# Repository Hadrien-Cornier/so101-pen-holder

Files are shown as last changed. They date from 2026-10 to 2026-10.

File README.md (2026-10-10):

# SO-101 pen holder

This is a printed sleeve that holds a pen on the stock gripper of the SO-101 robot arm. You print 4 small parts. You do not buy parts, and you do not take the arm apart.

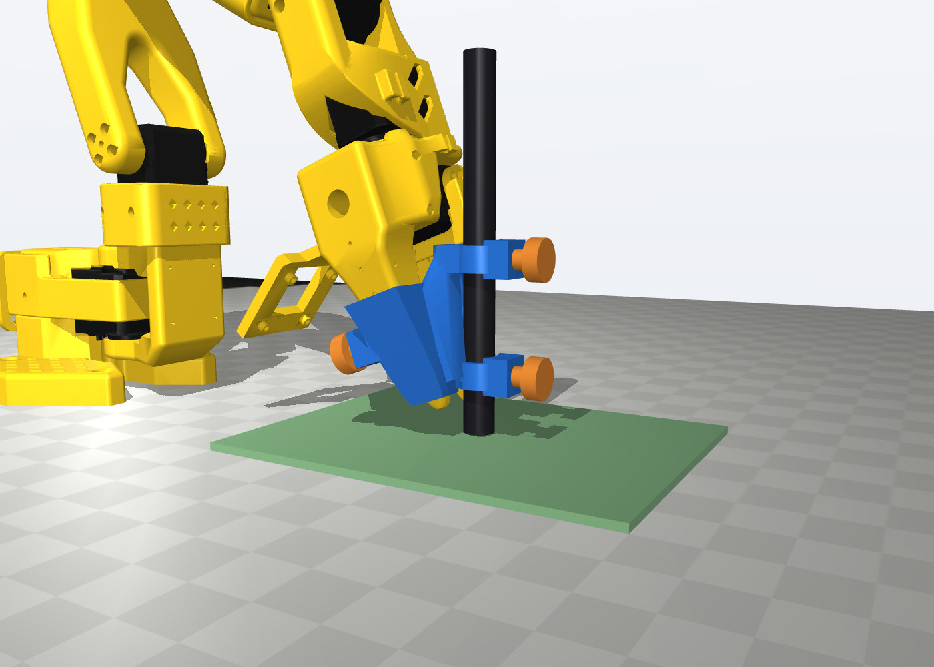
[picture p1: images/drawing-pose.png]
The SO-101 in a drawing pose with the pen holder. The blue sleeve is on the fixed finger, and the pen is vertical on the paper.


> [!NOTE]
> **Status: the first printed set fits, but nothing is measured yet.** The parts pass every collision check in CAD. The first set printed in PLA, the sleeve slid onto my finger, and the screws turned in on the first try, with no change to the design. I felt no play by hand. I have not measured the play, the tip position or the hold. Every number on this page is a design value, not a measurement. If you print the holder, you can report the result in an issue.

| | |
|---|---|
| Printed parts | 1 sleeve (27 g) and 3 identical M8 thumbscrews (2 g each) |
| Parts to buy | none |
| Pens | any round pen from 8 to 13 mm, for example a Wacom Pen 4K, a BIC 4-Colour or a Pilot V5 |
| Tablet | the Wacom Intuos S (CTL-4100), ±0.25 mm. See [Measure the tip with a Wacom tablet](#measure-the-tip-with-a-wacom-tablet). |
| Changes to the arm | none. The sleeve slides onto the fixed finger. |
| Fits | the stock SO-101 follower gripper (`Wrist_Roll_Follower_SO101`) |
| License | Apache-2.0 |

The holder on the stock gripper, from four sides. The blue sleeve is the printed part, and the orange parts are the printed thumbscrews:

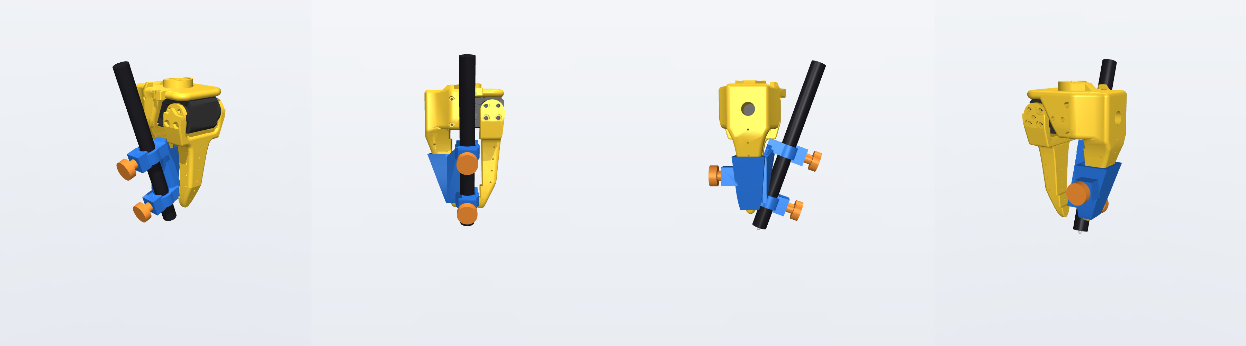
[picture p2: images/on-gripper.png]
The pen holder on the stock SO-101 gripper, seen from four sides


## The first print and the first fit

The first set is printed, and the sleeve is on my SO-101. The two pictures below play the full videos in a loop, with no sound. The MP4 files have a better quality.

<table>
<tr>
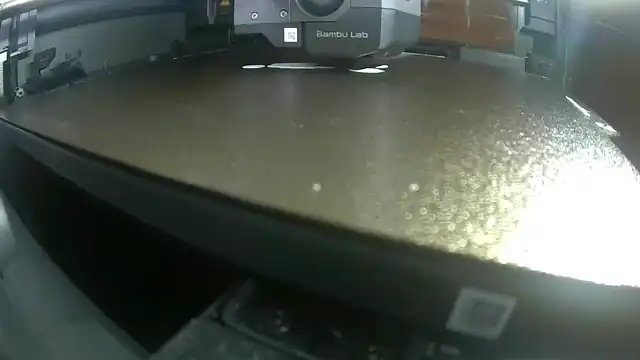
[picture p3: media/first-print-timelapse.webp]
Time-lapse of the print: four thumbscrews, two thread coupons and the sleeve grow on the bed of a Bambu Lab printer. The sleeve stands up on tree supports.
<td align="center" valign="middle"></td>
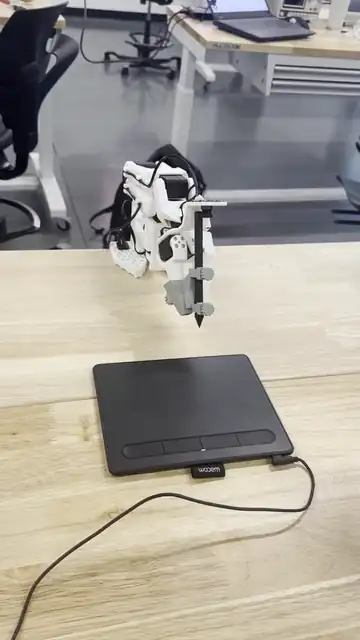
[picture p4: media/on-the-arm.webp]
The printed sleeve on the fixed finger of the SO-101. A pen is in both clamps, and the Wacom Intuos S tablet is in front of the arm.
<td align="center" valign="middle"></td>
</tr>
<tr>
<td align="center"><b>The print</b>, 15 s time-lapse<br><a href="https://github.com/Hadrien-Cornier/so101-pen-holder/raw/main/media/first-print-timelapse.mp4">Download the MP4</a> (3.4 MB)</td>
<td align="center"><b>The holder on the arm</b>, 13 s<br><a href="https://github.com/Hadrien-Cornier/so101-pen-holder/raw/main/media/on-the-arm.mp4">Download the MP4</a> (2.6 MB)</td>
</tr>
</table>

What the videos show:

- **The print.** A Bambu Lab printer makes the 4 thumbscrews, two thread coupons and the sleeve in one job. The screws print head down. The sleeve stands up, and the printer builds tree supports under it.
- **The holder on the arm.** The sleeve is on the stock fixed finger, and the pen is in both clamps with a thumbscrew on each clamp. The Wacom Intuos S is in front of the arm, and the pen tip is above it.

The result of the first try:

- **The sleeve fitted.** It slid onto the stock fixed finger with no filing and no change to the design.
- **The screws fitted.** They turned in on the first try, with no change to `FIT_THREAD`.
- **No play by hand.** I felt no play at the pen. This is a hand test, not a measurement.
- **The printer followed the settings.** The first set printed in PLA with the settings in [Print the parts](#print-the-parts).

I have not measured these points yet: the play at the tip, the tip position, the hold of the sleeve in the down direction, and a reading on the tablet. The videos show no drawing and no tablet reading. The [Limits](#limits) section lists the open points.

## Why a pen on a robot arm

A drawing is a simple test of how accurately an arm follows a path. When the arm leaves the path, the line on the paper shows it. You can see the error without a log file or a plot, and you can compare two controllers on the same sheet.

I use this test in my SO-101 control project. In a typical drawing pose, an error of 1 mrad on every joint moves the pen tip by about 0.3 mm on the paper. With the joint errors of my best controller, I expect a drawing error of about 1.2 mm RMS.

The test works only if the holder adds no error of its own. My first pen was taped into the gripper. It had two problems:

- **The pen moved in the tape.** When the paper pulled on the tip, the pen moved, and that movement looked like an arm error.
- **The tip position was not known.** My best fit of the tip position had a residual of 3 mm. That is more than the error that I want to see.

I searched GitHub, the SO-ARM100 repository, Printables, Thingiverse, MakerWorld, Cults3D and the LeRobot forum. I found grippers and camera mounts, but no pen holder for the SO-100 or the SO-101. So I designed one.

Ink shows the shape of an error, but it gives no numbers and no times. To measure the tip, I also bought a Wacom drawing tablet. The holder takes its pen. The section [Measure the tip with a Wacom tablet](#measure-the-tip-with-a-wacom-tablet) explains why.

The holder has five goals:

| Goal | Why |
|---|---|
| No play between the pen and the arm | The paper drag must not move the pen in the holder. |
| A known tip position | The arm model must know where the tip is. A guess adds an error to every point. |
| Any common pen | You can use the pen that you have, and a Wacom pen on a drawing tablet. |
| Nothing to buy, no change to the arm | Anybody with an SO-101 can try it in an afternoon. |
| A small print | A short print time and a small risk of a failed print. |

## Why this design

I made five designs. Each design fixed a problem of the one before it. The image shows all five with the same camera.

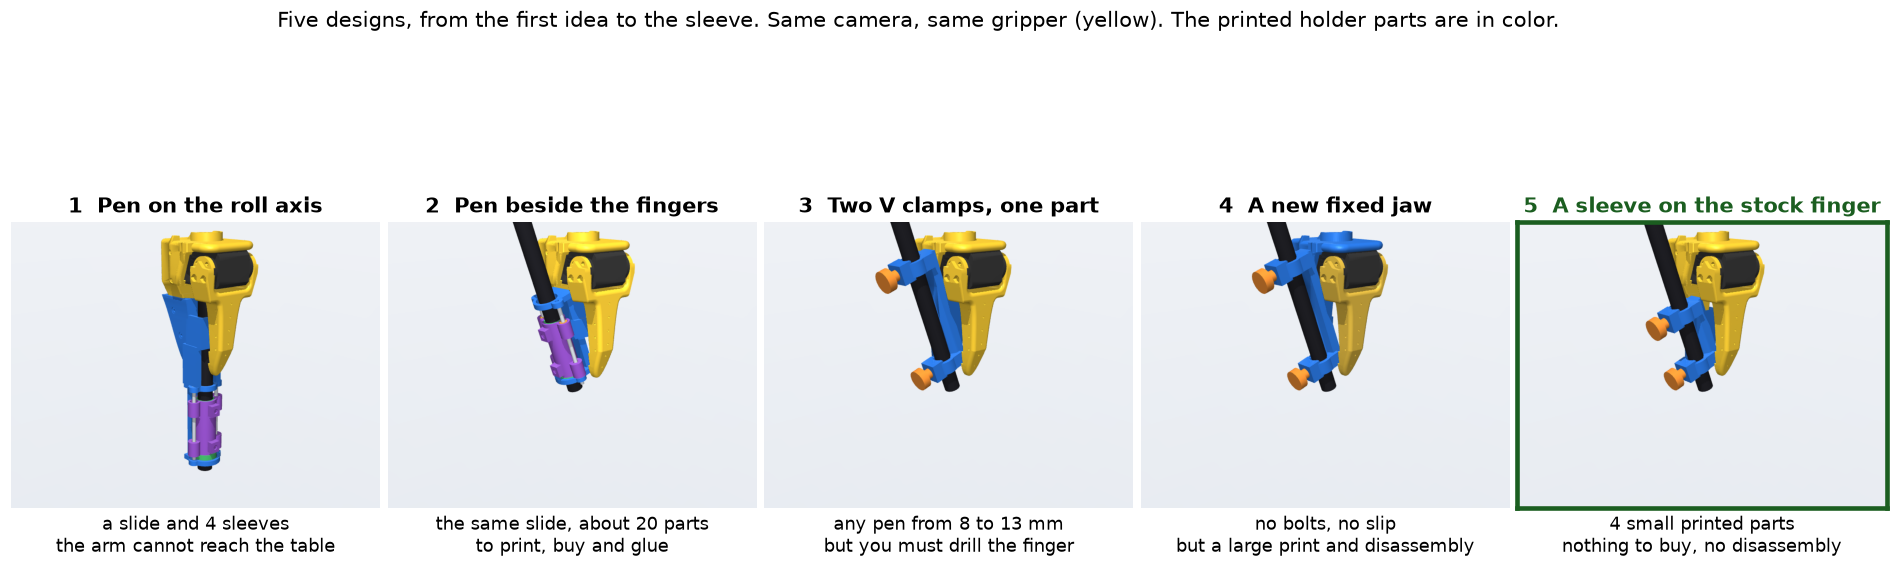
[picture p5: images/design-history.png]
Five designs on the same gripper with the same camera: the pen on the roll axis, the pen beside the fingers, two V clamps on one part, a new fixed jaw, and the sleeve on the stock finger.


1. **The pen on the roll axis.** The pen went down through the gripper, on a slide that let it rest on the paper by its own weight. On the full arm model, the arm could not reach a table at the level of its base.
2. **The pen beside the fingers.** I compared seven ways to attach the pen. The best layout puts the pen beside the fingers and leans it 20° out of the open side of the jaws. It reaches the most paper, and the tip stays 6 mm from the roll axis. But the slide needed about 20 parts: printed parts, steel shafts, bronze bushings and glue.
3. **Two V clamps on one part.** I removed the slide. A soft pad under the paper does its job. Two V clamps hold the pen at two points far apart, so the pen cannot tilt. One clamp design fits every pen from 8 to 13 mm. But to hold the part on the finger, you had to drill two holes in the finger for metal bolts.
4. **A new fixed jaw.** I joined the clamps to a copy of the official fixed jaw. Nothing can slip, but it is a large print, and you must take the gripper apart to change the jaw.
5. **A sleeve on the stock finger.** The clamps sit on a small sleeve that slides onto the finger. This is the design in this repository.

The last choice was between three ways to attach the same clamps:

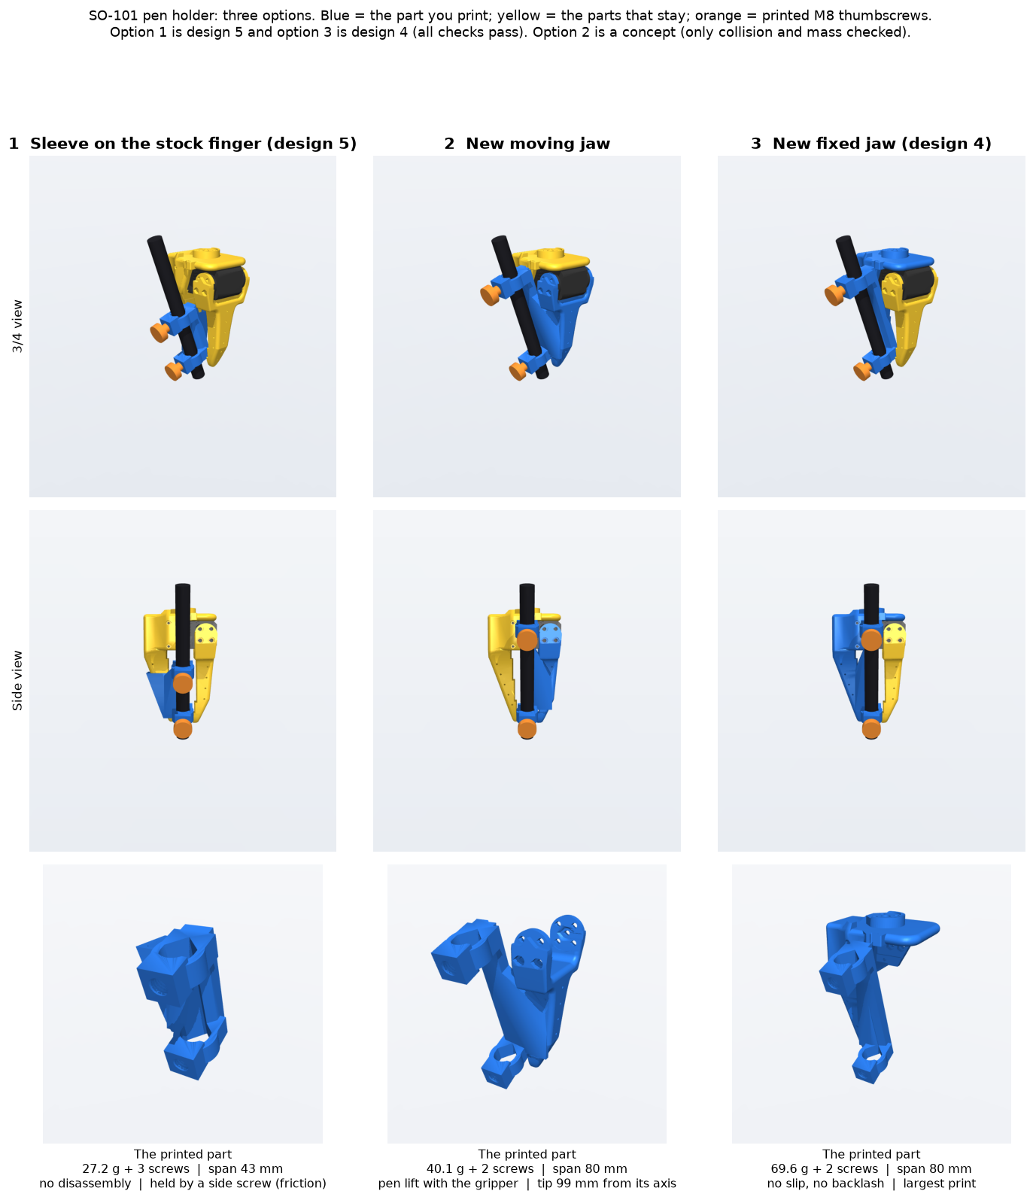
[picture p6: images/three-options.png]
The three final options side by side: a sleeve on the stock finger, a new moving jaw, and a new fixed jaw. The printed part is blue.


| | Sleeve on the finger (this design) | New moving jaw | New fixed jaw |
|---|---|---|---|
| Printed plastic | 34 g | 44 g | 74 g |
| Take the gripper apart | no | the moving jaw | the full gripper |
| Hold on the arm | wedge seat and friction | jaw screws | jaw screws |
| Play at the tip | none in the clamps | the backlash of the gripper motor, unless the jaw presses on a stop | none |
| Distance between the clamps | 43 mm | 80 mm | 80 mm |

I chose the sleeve for three reasons:

- **Anybody can try it.** You add one module to an arm that you already have. You do not open the gripper, and you can remove the sleeve in a minute.
- **It is the smallest print.** It uses less than half the plastic of a new fixed jaw.
- **The main load makes the hold tighter.** When the pen touches the paper, the paper pushes the sleeve up onto its seat on the finger.

The cost of the sleeve is a shorter distance between the clamps (43 mm), and a hold in the down direction that uses friction only. The [Limits](#limits) section gives the details.

## What you need

- An FDM 3D printer and about 34 g of filament. The first set printed in PLA and fitted. I did not compare filaments, so I do not recommend one.
- A soft pad, 2 to 5 mm thick, to put under the paper. For example, use a mouse pad, a felt sheet or thin foam. The pen is fixed in the holder, so the pad takes up small errors in the height of the arm. On a Wacom tablet, do not use the pad.
- A stock SO-101 follower arm. The optional compliant gripper has a different finger, and the sleeve does not fit it.

## Print the parts

The files are in [`print/`](print/). Each file is already placed in its print orientation, so do not turn it in the slicer:

| File | Quantity | Mass | Purpose | Print orientation |
|---|---|---|---|---|
| [`thread_coupon.stl`](print/thread_coupon.stl) | 1 | 2 g | A short piece of the M8 thread, to test the screw fit on your printer | The hole is horizontal, like the thread holes of the sleeve. |
| [`thumbscrew.stl`](print/thumbscrew.stl) | 3, and 1 spare | 2 g each | Two screws press the pen into the clamps. One screw presses the finger. | Head down |
| [`sleeve.stl`](print/sleeve.stl) | 1 | 27 g | The sleeve with the two pen clamps | Pen axis vertical, tip end up |

The first set printed in PLA with these settings, and it fitted on the first try. I did not compare other settings:

| Setting | Value | Why |
|---|---|---|
| Layer height | 0.2 mm | The usual value for a 0.4 mm nozzle. Thinner layers give smoother threads, but the print takes longer. |
| Walls | 4, which is 1.6 mm | The clamp rings (3 mm) and the side walls (2.6 mm) become solid, and the threads (0.68 mm deep) are in solid plastic. |
| Infill | 40 % for the sleeve and the coupon, 100 % for the screws | The infill changes only the thick areas. A solid screw is stronger, and it is only 2.1 g of plastic. |

The masses in the table use 4 walls and 40 % infill.

### Supports for the sleeve

The print orientation of `sleeve.stl` keeps the supports off the faces that set the pen position. The sleeve stands on the end of the upper thread boss. Red faces need support:

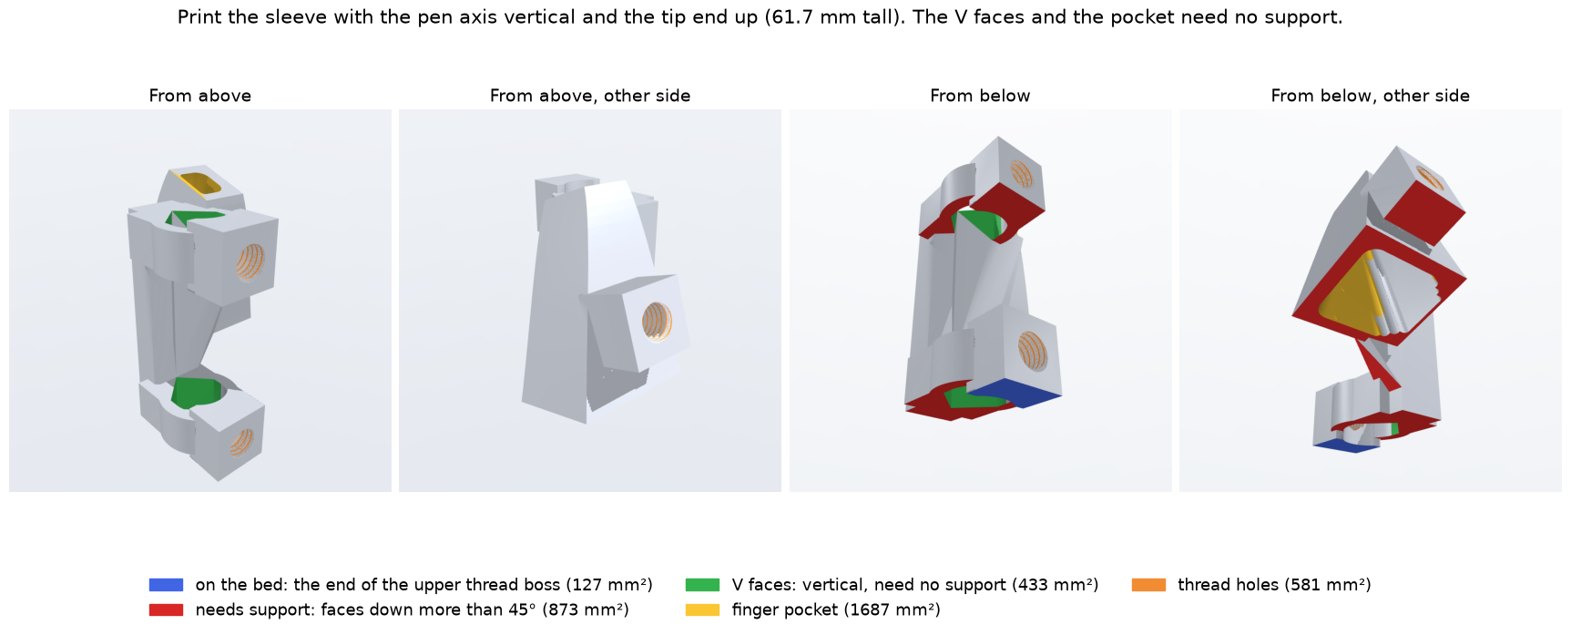
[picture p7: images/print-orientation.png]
The sleeve in its print orientation, from above and from below. Red faces need support. The green V faces and the yellow finger pocket need none. The blue face stands on the bed.


- **The V faces need no support.** They are vertical in this orientation. A support mark of 0.2 mm on a V face of the lower clamp would move the tip by about 0.3 mm.
- **The finger pocket needs no support.** The pocket has only 0.15 mm of clearance, so support marks in it would stop the sleeve from sliding onto the finger.
- **The supports stand outside the pocket.** [`cad/print_orientation.py`](cad/print_orientation.py) traces a column down from each face that needs support. Of 873 mm² of these faces, 586 mm² have columns on the bed and 287 mm² have columns on outside faces of the sleeve. No column passes through the pocket.
- **Block the supports in the three thread holes.** The holes are 8 mm wide and horizontal, and supports would damage the threads.
- **Use a brim.** The sleeve is 62 mm tall and stands on a face of only 127 mm².

The support analysis comes from the CAD model. The first print used this orientation and these support rules, and the sleeve and the screws fitted. That is one print on one printer, and I did not print the other orientations. The check uses a limit of 45° from vertical for supports, and your slicer can use a different limit. [`results/print_orientation.json`](results/print_orientation.json) compares 8 orientations.

### Print order

1. Print `thread_coupon.stl` and one `thumbscrew.stl`.
2. Turn the screw into the coupon by hand.
3. If the screw is too tight or too loose, change `FIT_THREAD` in [`cad/build.py`](cad/build.py). Then [rebuild the parts](#rebuild-the-parts) and print the coupon again.
4. Print `sleeve.stl` and three more thumbscrews. One screw is a spare.

## Fit the holder

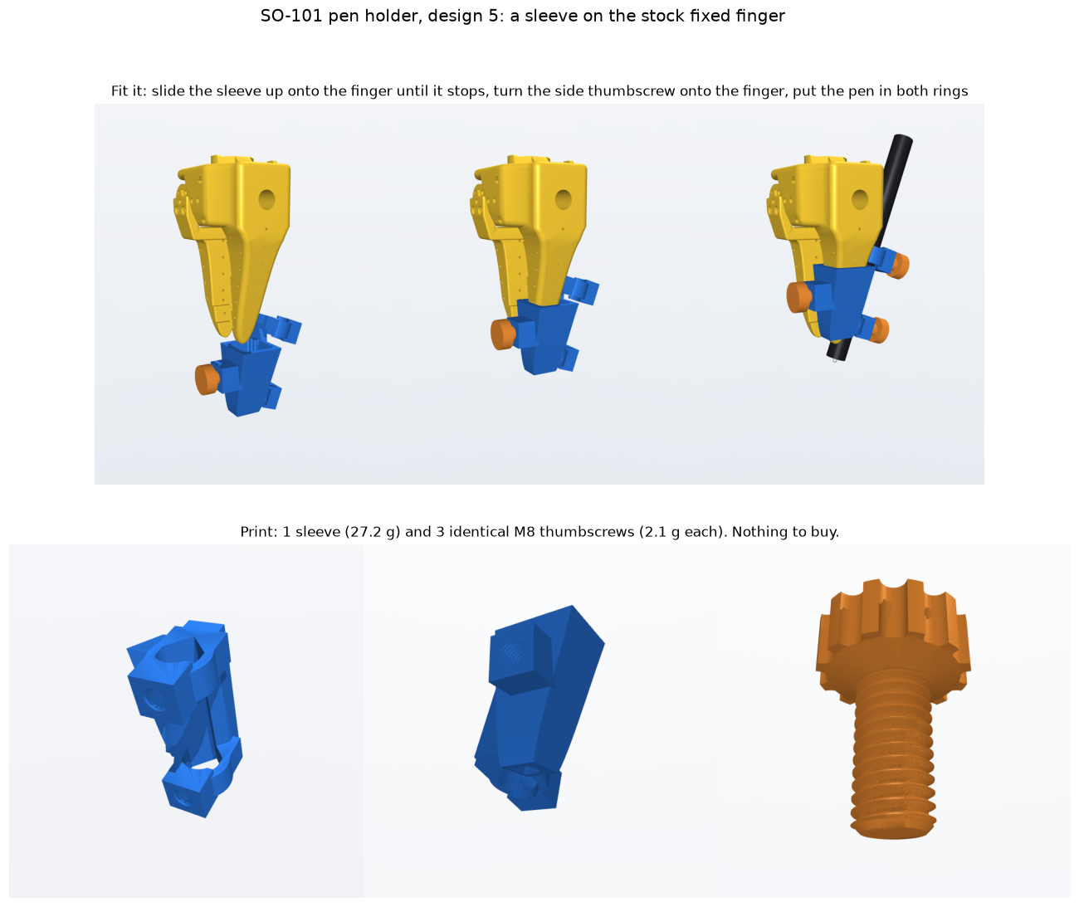
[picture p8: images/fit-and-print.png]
Top: the sleeve slides up onto the stock fixed finger, then the pen goes into both rings. Bottom: the printed sleeve and the thumbscrew.


1. Open the gripper fully.
2. Slide the sleeve up onto the end of the fixed finger until it stops. The two pen clamps go on the open side of the jaws.
3. Turn the side thumbscrew until it is tight on the finger.
4. Push the pen through both clamp rings.
5. Set the pen tip 21 mm below the bottom face of the lower ring, measured along the pen. That puts the tip at the design position for every pen.
6. Turn each pen thumbscrew until it touches the pen. Then turn it a quarter turn more.
7. Put the soft pad under the paper.

> [!CAUTION]
> Do not command the gripper to close fully while the sleeve is on the finger. The moving jaw touches the lower clamp ring at 0.015 rad from closed. If the motor pushes harder, it presses on the ring.

## How the holder works

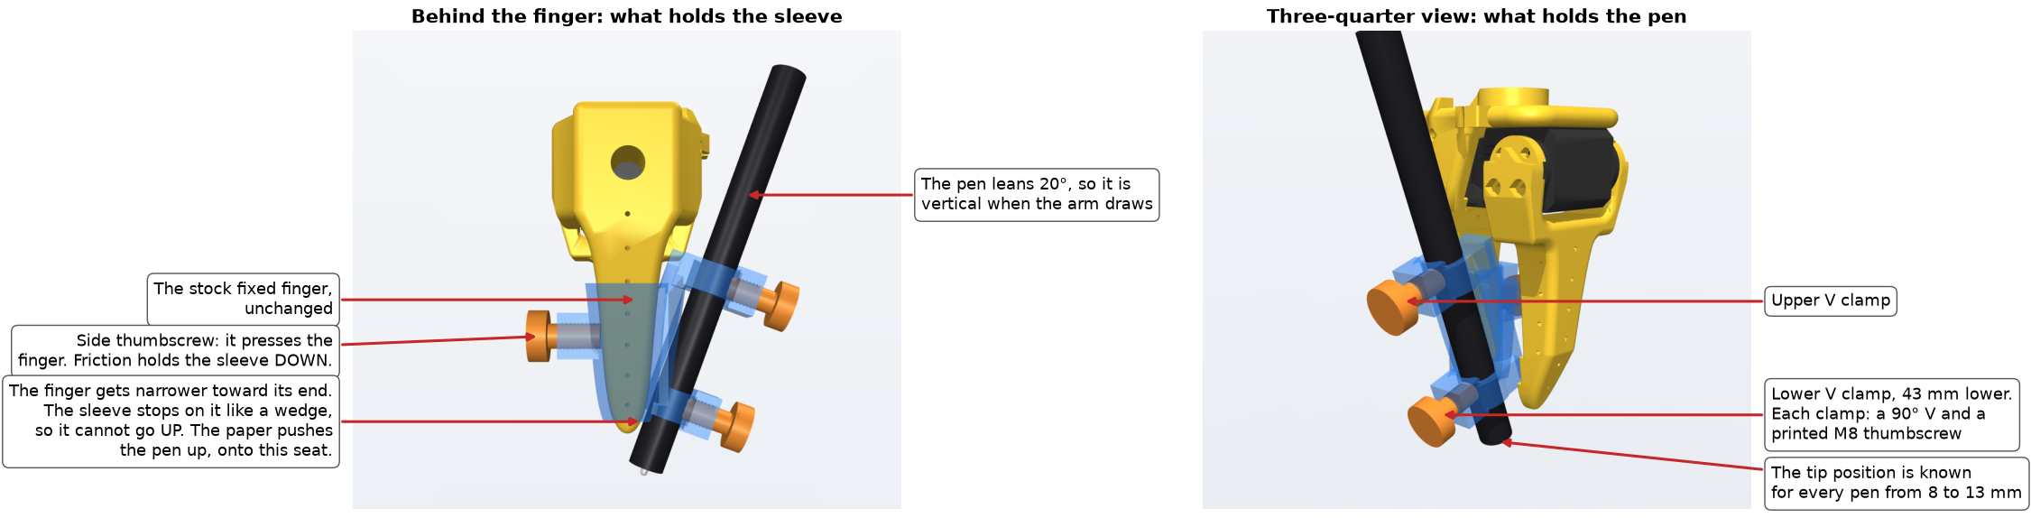
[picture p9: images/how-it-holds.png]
Left: a view from behind the fixed finger. The sleeve is see-through, so the finger shows inside it. Right: a three-quarter view of the two pen clamps.


The sleeve holds on the finger in three directions:

- **Up:** the finger gets narrower toward its end in both directions. The pocket of the sleeve has the shape of the finger, so the sleeve stops on it like a wedge. The paper pushes the pen up, which pushes the sleeve harder onto this seat.
- **Down:** the side thumbscrew presses one side of the finger and pushes the other side against the inner wall of the sleeve. Friction on both sides holds the sleeve. A hand-tight printed M8 screw probably presses with 50 to 100 N. With a friction coefficient of about 0.3 on two faces, the hold is about 30 to 60 N. The sleeve, the screws and a pen weigh about 0.45 N. These are estimates, not measurements.
- **Sideways:** the pocket fits the finger with 0.15 mm of clearance. The side screw removes the clearance in its direction. The wedge seat removes it in the other directions when the paper pushes up.

The pen is held by two clamps 43 mm apart. Each clamp is a ring with a 90° V on the gripper side and a printed M8 thumbscrew on the other side. The screw pushes the pen into the V. A round pen in a V touches it on two lines, so it can sit in only one position. There is no play to remove.

## Pens and the tip position

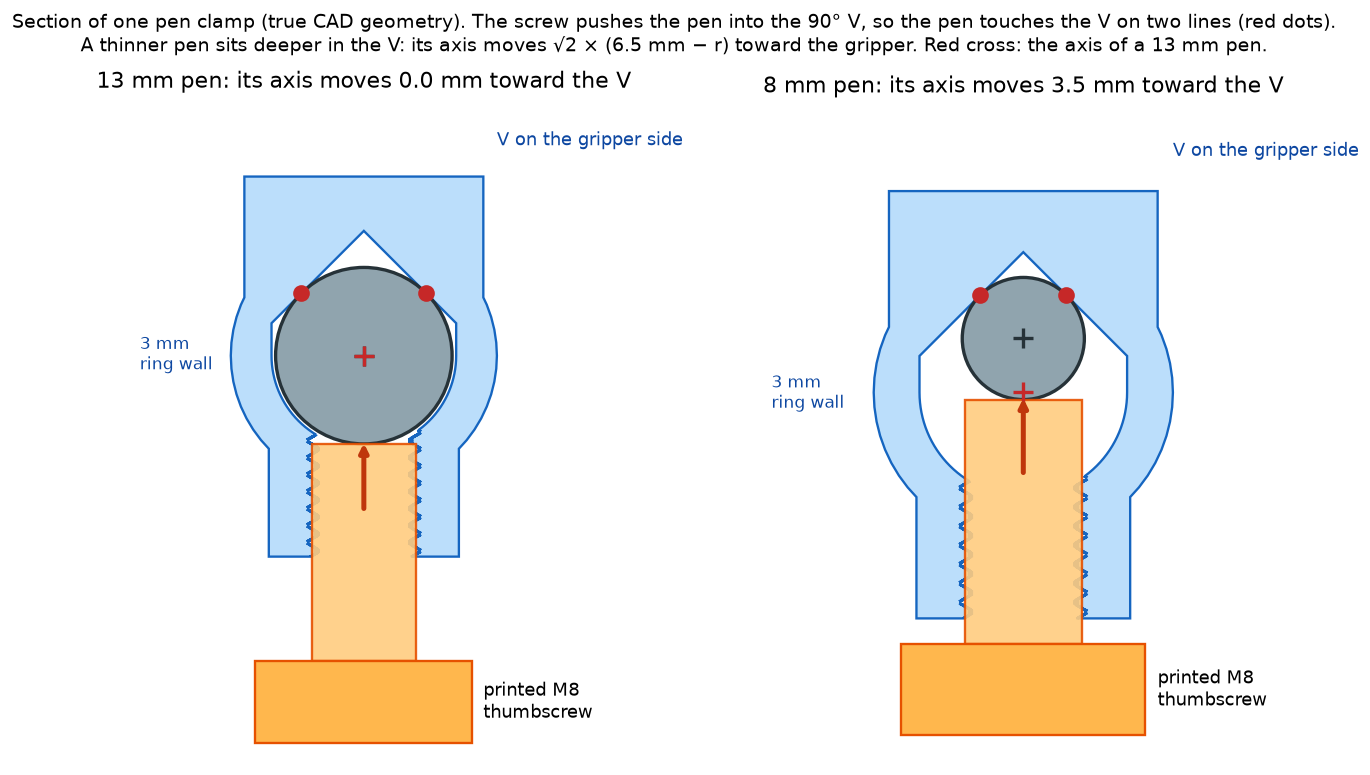
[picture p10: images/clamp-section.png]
Section of one clamp from the CAD model, with a 13 mm pen on the left and an 8 mm pen on the right.


A thinner pen sits deeper in the V. Its axis moves toward the gripper by:

$$
\text{shift} = \sqrt{2}\,(6.5\ \text{mm} - r)
$$

where r is the radius of the pen. So the tip position is known for every round pen. The table gives the tip position in the frame of the `gripper` body of the SO-101 MuJoCo model ([MuJoCo Menagerie](https://github.com/google-deepmind/mujoco_menagerie/tree/main/robotstudio_so101)). In that frame, z is the wrist_roll axis and the fingers point to −z.

| Pen | Diameter | Axis shift | Tip position (x, y, z), mm | Tip off the roll axis |
|---|---|---|---|---|
| 13 mm pen | 13.0 mm | 0.00 mm | (0, −6.00, −120.00) | 6.00 mm |
| Wacom Pen 4K (LP1100K) | 12.0 mm | 0.71 mm | (0, −5.34, −119.76) | 5.34 mm |
| BIC 4-Colour | 11.6 mm | 0.99 mm | (0, −5.07, −119.66) | 5.07 mm |
| Pilot V5 | 10.6 mm | 1.70 mm | (0, −4.41, −119.42) | 4.41 mm |
| 10 mm pen | 10.0 mm | 2.12 mm | (0, −4.01, −119.27) | 4.01 mm |
| 8 mm pen | 8.0 mm | 3.54 mm | (0, −2.68, −118.79) | 2.68 mm |

For another pen, measure its diameter at the two clamps with calipers. Then use these values:

- The tip of a 13 mm pen is at (0, −6, −120).
- The axis shift is along (0, cos 20°, sin 20°).
- The pen axis, from the tip up, is (0, −sin 20°, cos 20°).

If the pen is tapered, the two clamps see two diameters, and the pen tilts a little. Measure both diameters.

## Measure the tip with a Wacom tablet

I bought a Wacom Intuos S drawing tablet (model CTL-4100, wired) on 5 October 2026. A drawing tablet senses the position of its own pen, without contact. The holder takes this pen, the Wacom Pen 4K (LP-1100K).

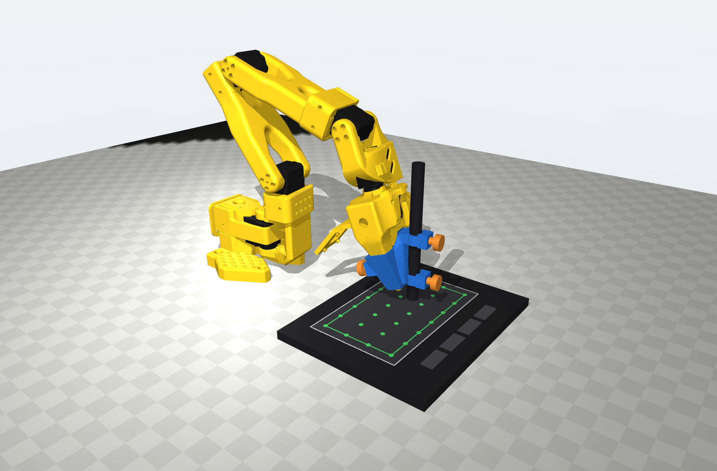
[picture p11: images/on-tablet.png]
The SO-101 draws on the Wacom Intuos S, in the arm model. The white line is the active area of the tablet. The green line is the usable area, 10 mm inside it. The arm reaches all 28 green points with the pen vertical.


### Why I bought this tablet

I bought it for four reasons:

- **It measures the tip, not the joints.** The joint encoders measure the joint angles. The arm model then calculates the tip, so the encoders cannot see bending, gear play or errors in the model. The tablet measures the tip itself.
- **It records the time.** The tablet sends the tip position 133 times per second. That is more than 2 times the 60 Hz control rate of the arm. So I can align the tablet data with the arm log and see when the arm is late, not only where it goes.
- **Its tolerance is small compared with the error.** Wacom gives ±0.25 mm. I expect a drawing error of about 1.2 mm RMS, and 1 mrad on every joint moves the tip by about 0.3 mm.
- **It is cheap, and it adds nothing to the arm.** It costs about 40 USD. The pen has no battery and no cable, so no wire pulls on the arm.

### The tablet values

The table gives the values from the [Wacom Intuos technical specifications](https://www.wacom.com/en-us/products/pen-tablets/wacom-intuos) and the [Wacom Important Product Information for the CTL-4100](https://files.bbystatic.com/MNDaVNuYo7JVwmFl9W/83Q==/0ba65b21-5c0c-4265-b501-8495091d22c5.pdf) (a copy on the Best Buy site). I read both on 7 October 2026.

| Property | Value |
|---|---|
| Accuracy | ±0.25 mm at the center of the tablet. Wacom calls it the "digital tolerance in accuracy". |
| Resolution | 2540 lines per inch, which is 0.01 mm |
| Report rate | 133 per second |
| Reading height | 7 mm above the surface, at the center |
| Active area | 152 × 95 mm |
| Tablet size | 200 × 160 × 8.8 mm |
| Pressure levels | 4096 |
| Pen | Wacom Pen 4K (LP-1100K), 11.2 g, no battery, no ink |

Wacom gives the ±0.25 mm and the 7 mm reading height for the center of the tablet only. It gives no value for the edges or for a tilted pen. So I use two rules:

- **Keep the drawing 10 mm inside the active area.** Wacom gives no value for the edges, and other makers publish a larger error at the edges. The usable area is then 132 × 75 mm.
- **Keep the pen vertical.** The coil of the pen is above the nib, so a tilted pen moves the reading. The Intuos S does not measure the tilt, so it cannot correct it. The holder keeps the pen vertical in the drawing pose.

### Put the tablet under the arm

1. Put the center of the active area 181 mm in front of the `shoulder_pan` axis, with the long side across the arm. That is about 155 mm in front of the front edge of the base.
2. Tape or clamp the tablet to the table. Do not put the soft pad under the tablet, because the tablet must not move.
3. In your arm model, set the drawing surface 8.8 mm above the table.
4. Put the Pen 4K in the holder as in [Fit the holder](#fit-the-holder). Its tip position is in the [pen table](#pens-and-the-tip-position).

Without the soft pad, a height error of the arm pushes the pen into the tablet or lifts it. You can use the tablet in two ways:

- **Hover:** command the tip 2 to 3 mm above the surface. The tablet reads the pen up to 7 mm away, and there is no drag. Wacom does not publish the accuracy in hover.
- **Contact:** let the tip touch the surface. The tablet also records the pen pressure, so you know when the pen touches.

In the arm model, the arm reaches the full usable area. With the pen vertical, an inverse kinematics solution exists at all 28 points of a 4 × 7 grid, at contact and at 3 mm hover. The lowest point of the arm stays 20 mm above the tablet. These values come from the [MuJoCo Menagerie SO-101 model](https://github.com/google-deepmind/mujoco_menagerie/tree/main/robotstudio_so101), not from the real arm. The results are in [`results/tablet_reach.json`](results/tablet_reach.json).

The [videos](#the-first-print-and-the-first-fit) show the tablet in front of the arm, but I did not record a reading with the arm yet. The first tests are the noise of a still pen with the servos off and on, the reading at hover heights from 0 to 7 mm, and the effect of the servo magnets near the pen.

## What the CAD checks

[`cad/build.py`](cad/build.py) builds the parts from parameters and checks them against the stock gripper meshes. It writes the results to [`results/checks.json`](results/checks.json). These checks pass:

- The sleeve does not touch the fixed finger, the gripper motor or the moving jaw anywhere from 0.3 to 1.4 rad.
- The sleeve slides 60 mm up onto the finger with no contact, with the gripper open.
- The moving jaw stops on the lower clamp ring at 0.015 rad from closed.
- Six pens from 8 to 13 mm do not touch the sleeve or the gripper.
- The three screws mesh with their threads, and their heads stay clear of their bosses.
- The lowest point of the sleeve is 14 mm above the tip, so only the tip touches the paper.
- In the print orientation of `sleeve.stl`, the V faces and the finger pocket need no support, and no support column passes through the pocket. [`cad/print_orientation.py`](cad/print_orientation.py) runs this check.

The clamp rings and the side walls of the sleeve are 2.6 to 3 mm thick. The front skin of the sleeve, between the finger and the pen, is 0.85 mm thick. It must be thin, because the pen passes close to the finger, and it carries almost no load.

## Limits

- **One printed set, not measured.** The sleeve is printed once and is on one arm. It slid on and the screws turned in on the first try, and I felt no play by hand. I did not measure the play, the tip position or the hold yet. The pocket comes from the official CAD of the finger. If your printed finger is a little larger or smaller, the fit changes. Test the sleeve on the finger before you put the pen in.
- **Friction in the down direction.** Nothing locks the sleeve positively in the down direction. A hard knock can move it, and plastic creeps with time. Tighten the side screw before each session.
- **A short clamp span.** The finger is short, so the clamps are only 43 mm apart. The V clamps have no play, but I did not calculate how much the sleeve bends under the paper drag.
- **The printed threads.** Plastic threads wear after many pen changes. If a thread wears out, print a new screw. If the hole wears out, print a new sleeve.

## Rebuild the parts

I tested the build with Python 3.12 on macOS.

```bash
python3 -m venv .venv
```

```bash
.venv/bin/pip install -r cad/requirements.txt
```

```bash
.venv/bin/python cad/build.py
```

The build takes about one minute. It writes `print/*.stl`, the sleeve in the gripper frame (`results/sleeve_in_gripper_frame.stl`) and `results/checks.json`. It exits with code 1 if a check fails. To check the print orientation, run `.venv/bin/python cad/print_orientation.py` after the build. All the dimensions are constants at the top of [`cad/build.py`](cad/build.py). To draw the clamp section again, install `matplotlib` and run `cad/figure_clamp_section.py`.

## The full story

The article [A pen holder that shows the arm's error, not its own](https://hadrien-cornier.github.io/robotics/so101-pen-holder/) explains every design, the layout comparison, and the numbers behind each choice. It is part 5 of the series *From policy to action: the last mile of robotics control*.

## License and credits

The design is licensed under the [Apache License 2.0](LICENSE).

The gripper meshes in [`cad/meshes/`](cad/meshes/) are copied without change from [MuJoCo Menagerie](https://github.com/google-deepmind/mujoco_menagerie) (Apache-2.0). They come from the [SO-ARM100](https://github.com/TheRobotStudio/SO-ARM100) CAD by TheRobotStudio (Apache-2.0). The [`NOTICE`](NOTICE) file and [`cad/meshes/PROVENANCE.md`](cad/meshes/PROVENANCE.md) give the details.

The SO-101 is a design of TheRobotStudio and Hugging Face. This project is not affiliated with them.

Author: [Hadrien Cornier](https://github.com/Hadrien-Cornier).

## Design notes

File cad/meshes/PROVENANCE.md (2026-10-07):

# Gripper meshes

These files are copied byte for byte. Do not edit them.

- Source: MuJoCo Menagerie, https://github.com/google-deepmind/mujoco_menagerie
- Folder: `robotstudio_so101/assets/`
- Commit: `822c2d8f877dd166c5b7d3c9f7e3c3b6589473b7`
- License: Apache-2.0 (`LICENSE.mujoco_menagerie`). The upstream CAD comes from
  TheRobotStudio SO-ARM100, also Apache-2.0.

| File | Part | SHA-256 |
|---|---|---|
| `wrist_roll_follower_so101_v1.stl` | fixed jaw (`Wrist_Roll_Follower_SO101`) | `4b17b410a12d64ec39554abc3e8054d8a97384b2dc4a8d95a5ecb2a93670f5f4` |
| `moving_jaw_so101_v1.stl` | moving jaw | `785a9dded2f474bc1d869e0d3dae398a3dcd9c0c345640040472210d2861fa9d` |
| `sts3215_03a_v1.stl` | gripper motor (STS3215) | `a37c871fb502483ab96c256baf457d36f2e97afc9205313d9c5ab275ef941cd0` |

The fixed-jaw mesh matches the official print STL
(`STL/SO101/Individual/Wrist_Roll_Follower_SO101.stl` in SO-ARM100) with a mean
gap of 0.0035 mm and a largest gap of 0.07 mm.

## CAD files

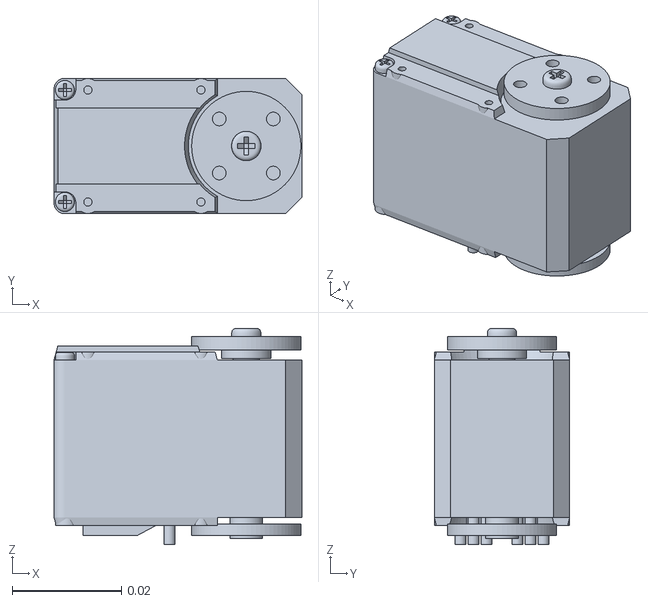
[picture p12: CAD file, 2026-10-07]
cad/meshes/sts3215_03a_v1.stl
0.0454 x 0.0248 x 0.0396

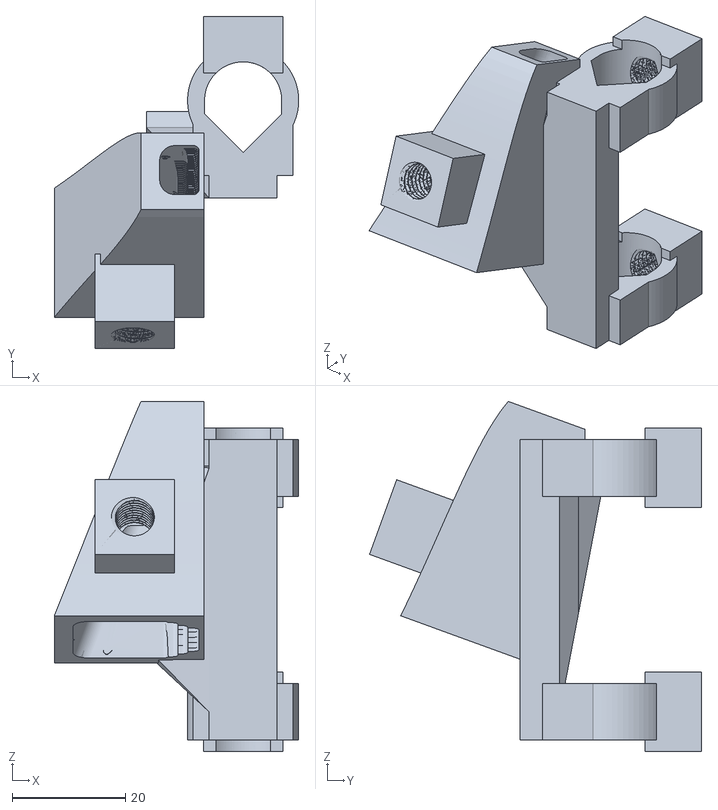
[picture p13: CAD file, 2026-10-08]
print/sleeve.stl
43.1 x 58.5 x 61.7

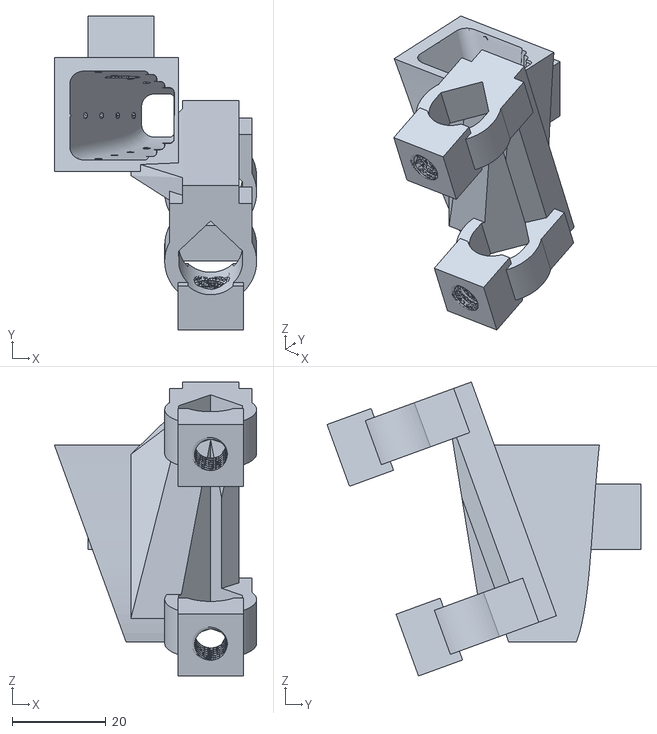
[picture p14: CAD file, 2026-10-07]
results/sleeve_in_gripper_frame.stl
43.1 x 66.9 x 62.6

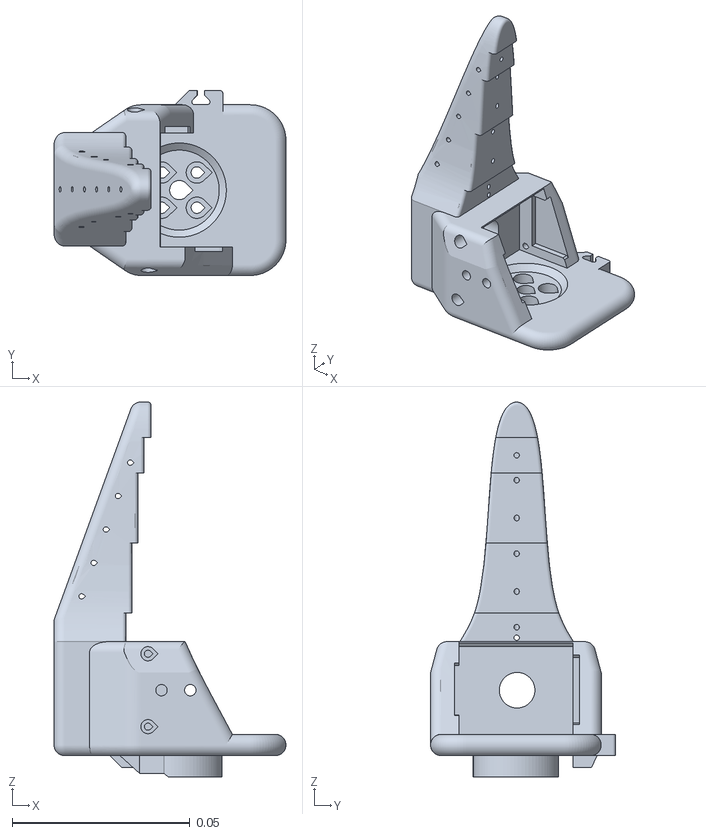
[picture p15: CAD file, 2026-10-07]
cad/meshes/wrist_roll_follower_so101_v1.stl
0.0652 x 0.052 x 0.105

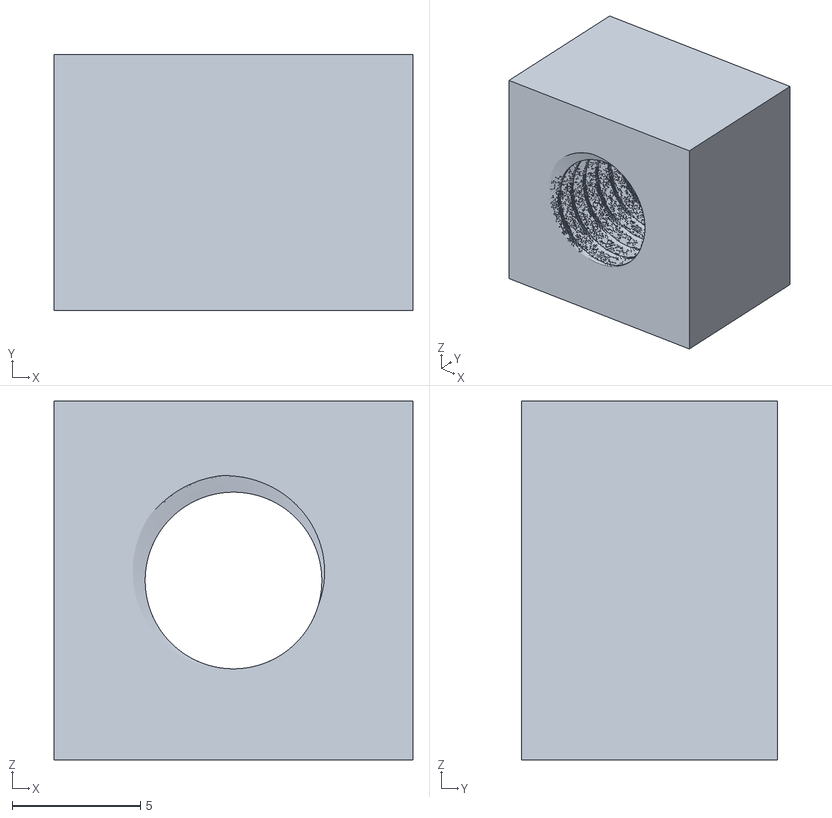
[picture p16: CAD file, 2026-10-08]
print/thread_coupon.stl
14.0 x 10.0 x 14.0

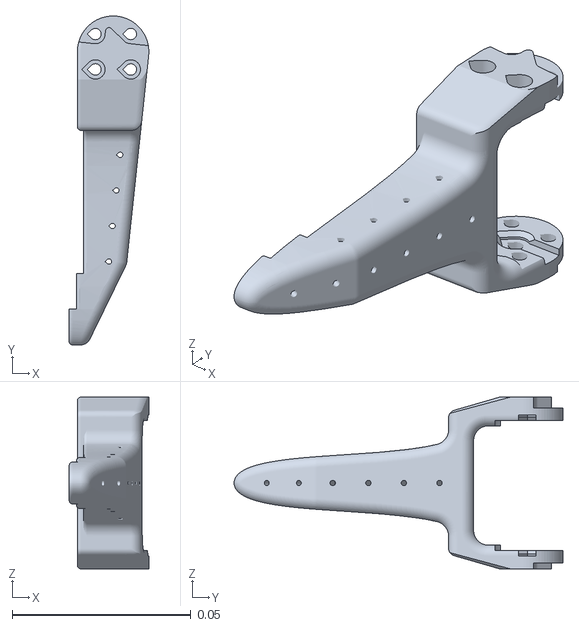
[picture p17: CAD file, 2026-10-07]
cad/meshes/moving_jaw_so101_v1.stl
0.0223 x 0.092 x 0.048

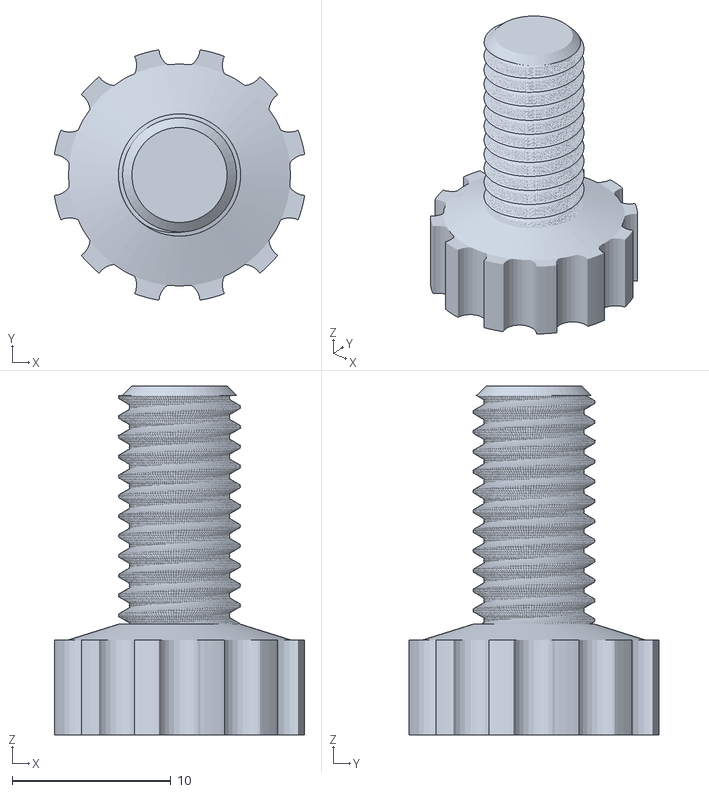
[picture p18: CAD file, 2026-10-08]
print/thumbscrew.stl
15.8 x 15.8 x 22.0

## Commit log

2026-10-07 Add the SO-101 pen holder: a printed sleeve for the stock gripper
    One sleeve and three identical printed M8 thumbscrews hold any round pen
    from 8 to 13 mm on the stock SO-101 fixed finger. Nothing to buy, and no
    change to the arm. cad/build.py builds the parts from parameters and checks
    them against the stock gripper meshes (MuJoCo Menagerie, Apache-2.0).
    [moving_jaw_so101_v1.stl, sleeve.stl, sts3215_03a_v1.stl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]
2026-10-07 README: show the holder from four sides; add scipy to the requirements
    A clean install showed that trimesh needs scipy to cut mesh sections.
2026-10-07 README: add the Wacom Intuos S tablet, its tolerance and why I use it
    The holder takes the Wacom Pen 4K of the Intuos S (CTL-4100). The new
    section gives the reasons for the tablet, the Wacom values (+/-0.25 mm,
    133 reports per second, 7 mm reading height), the setup under the arm,
    and an IK reach check of the usable area in the MuJoCo SO-101 model.
2026-10-07 README: Wacom states the +/-0.25 mm accuracy for the tablet center only
    Source: Wacom Important Product Information for the CTL-4100,
    "Pen Accuracy +/- 0.25mm (Center)".
2026-10-08 README: remove the untested PETG recommendation
    No filament is tested yet. The first holder will be printed in PLA.
2026-10-08 Place the print files in their print orientation; add the support check
    - print/sleeve.stl stands with the pen axis vertical and the tip end up,
    so the V faces and the finger pocket need no support.
    - print/thumbscrew.stl is head down. The coupon hole is horizontal.
    - results/sleeve_in_gripper_frame.stl keeps the sleeve in the gripper frame.
    - cad/print_orientation.py compares 8 orientations and traces the support
    columns. README: print settings, supports, and a spare screw.
    [sleeve.stl, sleeve_in_gripper_frame.stl, thread_coupon.stl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]
2026-10-10 README: add the first print and the first fit, with two videos
    - media/: the print time-lapse and the holder on the arm, as H.264 MP4
    (no sound, no metadata) and as short animated WebP previews.
    - Status: the first set is printed and on the arm; nothing is measured yet.
    - Remove the untested PLA/PETG statements and the 'not printed yet' limit.
2026-10-10 README: result of the first print
    The sleeve slid onto the finger and the screws turned in on the first
    try, with no change to the design. No play was felt by hand. Nothing is
    measured yet.
2026-10-10 README: the first print has two thread coupons
